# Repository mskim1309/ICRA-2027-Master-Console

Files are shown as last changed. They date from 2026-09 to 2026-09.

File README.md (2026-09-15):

# ICRA 2027 Master Console

This repository contains the design data, robot descriptions, manufacturing bill of materials, and assembly documentation for the master console presented in the accompanying ICRA 2027 paper. It is intended to support inspection, fabrication, and reproducible use of the hardware described in the paper.

> **Release status:** This repository is being prepared for the paper submission/review release. The final archival release will include the files and documentation listed below. Please use a tagged release when reproducing reported results.

## Repository layout

```text
.
├── CAD/                         # Native CAD source files
│   ├── distal_wrist/             # Distal-wrist mechanism
│   ├── grasp_module/             # Grasp/input module
│   ├── flange/                   # Robot/interface flange
│   └── console_frame/            # Main console frame and structural parts
├── URDF/                         # Robot descriptions for visualization/simulation
│   └── piper_with_custom_gripper.urdf         # PiPER arm + custom gripper urdf
├── STL/                          # Exported printable/manufacturable meshes
├── BOM/
│   └── BOM.xlsx                  # Purchased parts, quantities, and specifications
├── ASSEMBLY/
│   └── assembly_guide.pdf        # Assembly procedure and drawings
└── README.md
```

## Contents and intended use

| Directory | Contents | Intended use |
| --- | --- | --- |
| `CAD/` | Editable source models, organized by mechanical subassembly | Design inspection and modification |
| `STL/` | Mesh exports corresponding to released parts | Fabrication/3D-print preparation |
| `BOM/` | Part numbers, quantities, specifications, and procurement notes | Hardware sourcing |
| `ASSEMBLY/` | Ordered assembly instructions, fasteners, and reference drawings | Mechanical assembly |
| `URDF/` | Left and right kinematic descriptions | Visualization, simulation, and software integration |

## Reproducing the hardware

1. Review `BOM/BOM.xlsx` and obtain the listed purchased components before fabrication.
2. Fabricate the released parts from `STL/`, following the material, process, tolerance, and post-processing notes in the assembly guide.
3. Assemble the console using `ASSEMBLY/assembly_guide.pdf`. Do not infer dimensions or fasteners from mesh files when the guide specifies them.
4. Load the appropriate file from `URDF/` to verify the left/right configuration, link frames, joint axes, and mesh paths before connecting it to control software.
5. Record the repository tag/commit and any substitutions or fabrication deviations when reporting results.

## Important notes

- CAD source files are the authoritative editable design data. STL files are exports for fabrication and may be unsuitable for dimensional edits.
- All dimensions, units, coordinate-frame conventions, joint limits, mesh paths, and software dependencies will be documented with the final release. Validate them in your target simulator before operating hardware.
- The left and right consoles are separate URDF models. Do not assume that mirroring one file produces the correct frame conventions or joint signs for the other.
- This repository provides research hardware data only. Fabrication, integration, operation, and any safety assessment remain the responsibility of the user.

## Versioning and reproducibility

The version of this repository associated with the paper will be identified by a release tag. For a reproducible build or evaluation, cite the paper and record:

- repository URL and release tag (or commit SHA);
- CAD/URDF revision;
- BOM revision and any substituted components; and
- fabrication method, material, print settings, and post-processing changes.

## Citation

If you use this hardware, design data, or URDF models in academic work, please cite the associated paper:

```bibtex
@inproceedings{<citation-key>,
  title     = {<paper title>},
  author    = {<authors>},
  booktitle = {Proceedings of the IEEE International Conference on Robotics and Automation (ICRA)},
  year      = {2027},
  note      = {Paper submission / preprint; update with the final bibliographic record upon publication}
}
```

The final release will replace the placeholders above with the published citation and persistent repository URL.

## License and contact

License terms and a contact address will be added before public release. Until then, the contents are provided only for the paper-submission/review purpose; redistribution, fabrication, and commercial use require permission from the authors.

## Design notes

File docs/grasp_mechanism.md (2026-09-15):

# Grasp mechanism

Two finger levers on parallel pivots, geared to each other so they move
symmetrically. The operator squeezes them by hand.

**There is no motor and no CAN on this axis.** The levers are purely an input
device: a single magnetic rotary encoder on the lever shaft measures how far
they have been squeezed, and the console software turns that one number into the
patient-side instrument's jaw command. The two wrist axes above it are actuated;
this one is not.

## Parts

| part | file stem | role |
|---|---|---|
| Grasp lever 1 | `grasp_lever_1` | finger lever; gear teeth mesh with lever 2 |
| Grasp lever 2 | `grasp_lever_2` | finger lever; mirror of lever 1 |
| Grasp mount plate | `grasp_mount_plate` | carries the lever pair |
| Grasp pivot pins | `grasp_pin_1`, `grasp_pin_2` | lever pivots, 2 mm dia x 10.5 mm |
| Grasp sensor base | `grasp_sensor_base` | levers pivot in its centre holes; the encoder mounts on top |
| Grasp cover | `grasp_cover` | lever housing |
| MCU base | `mcu_base` | carries the XIAO board |

CAD for the two levers is in `../CAD/grasp_module/` (`grasp_lever_1`,
`grasp_lever_2`). `grasp_sensor_carrier` in the same folder holds the sensing
parts as three solids: the magnet (5 mm dia x 2 mm), the sensor IC and its PCB.
The other printed parts of the module are released as STL only.

## Kinematics

| joint | type | parent | axis | actuated |
|---|---|---|---|---|
| `gear_1_joint` | revolute | `link_2dof` | -X in the `link_2dof` frame | no — hand-driven |
| `gear_2_joint` | revolute | `link_2dof` | -X in the `link_2dof` frame | no — hand-driven |

The gear teeth constrain the pair, so one angle describes both. The software
publishes one lever angle and mirrors it onto the other (`gear_2 = -gear_1`).

**No joint limits are set in the CAD;** the travel is bounded by the parts
themselves. The URDF limits each lever joint to ±30° (0.5236 rad). Measured at
the encoder, the full travel has come out between about **20 and 36 degrees**
depending on the unit, so treat the range as something to measure per unit, not
a design constant.

The controller loads the URDF with both lever joints **locked at neutral**. That
is not bookkeeping: the dynamics library counts every unlocked joint, so leaving
the levers free changes the model's DOF count and breaks code that assumes the
arm's. Any joint added to the URDF beyond the wrist has to be locked the same way.

## Sensing

| | |
|---|---|
| encoder | AS5600-class magnetic rotary, 12-bit, 4096 counts per revolution |
| mounting | on the lever shaft, carried by `grasp_sensor_base` |
| front end | Seeed XIAO nRF52840 Sense on `mcu_base`, USB `2886:8045` |
| stream | about 167 Hz, CSV over USB CDC; the angle field is already in degrees |
| normalised output | 0.0 = fully open, 1.0 = fully closed |

Two things about this sensor decide whether the grasp feels right:

**The magnet wraps at 0/360.** The host driver unwraps the reading into a
cumulative angle, but if the lever's working range straddles the wrap point, a
squeeze right at the boundary makes the jaw jump open. Mount the magnet so the
whole travel sits away from the seam.

**The endpoints are per-unit, not per-design.** Fully-open and fully-closed
angles come from a calibration run on each assembled gripper. So do the sign and
the scale, because they depend on how the sensor is wired and which way the
magnet faces. None of these belong in the CAD or the URDF.

## Build checks

- The two levers move symmetrically. A half-tooth offset at assembly is a
  permanent bias the software cannot see.
- The encoder reading sweeps smoothly across the full lever travel. A reading
  that never moves by more than one count means the magnet is too far away or
  not centred.
- The travel does not cross the 0/360 seam.

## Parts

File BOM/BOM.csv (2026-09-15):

category | item | part_file | qty_per_hand | material_or_vendor | specification | source_of_value | notes | filament_g_per_hand_est | unit_cost_usd | cost_group_and_source
Printed part | Flange — PiPER link6 mount | STL/printable_right/flange_piper_mount.stl | 1 | PLA (Bambu PLA Basic) | 122.4 x 50.0 x 125.0 mm bbox; solid 154.46 cm3 | measured from mesh | Fixed joint link6_to_link_1dof; seats flat or wrist readings pick up a constant offset | 78.3 |  | Printed distal parts / fasteners, per console = ~60 (paper Table II)
Printed part | Wrist axis-1 yoke | STL/printable_right/wrist_axis1_yoke.stl | 1 | PLA (Bambu PLA Basic) | mass 80.84 g | URDF inertial (scaled to measured) | Carries the bases of both wrist servos (two 20 x 20 mm hole patterns in the CAD) | 81.6 |  | Printed distal parts / fasteners, per console = ~60 (paper Table II)
Printed part | Wrist axis-2 handle | STL/printable_right/wrist_axis2_handle.stl | 1 | PLA (Bambu PLA Basic) | mass 56.13 g | URDF inertial (scaled to measured) | Operator grip body | 58.9 |  | Printed distal parts / fasteners, per console = ~60 (paper Table II)
Printed part | Grasp lever 1 | STL/printable_right/grasp_lever_1.stl | 1 | PLA (Bambu PLA Basic) | 20.5 x 62.3 x 32.0 mm bbox; solid 6.02 cm3 | measured from mesh | Geared to lever 2; moves symmetrically | 7.1 |  | Printed distal parts / fasteners, per console = ~60 (paper Table II)
Printed part | Grasp lever 2 | STL/printable_right/grasp_lever_2.stl | 1 | PLA (Bambu PLA Basic) | 20.5 x 62.7 x 32.0 mm bbox; solid 6.02 cm3 | measured from mesh | Geared to lever 1 | 7.4 |  | Printed distal parts / fasteners, per console = ~60 (paper Table II)
Printed part | Grasp mount plate | STL/printable_right/grasp_mount_plate.stl | 1 | PLA (Bambu PLA Basic) | 24.0 x 42.5 x 5.0 mm bbox; solid 1.77 cm3 | measured from mesh |  | 3.2 |  | Printed distal parts / fasteners, per console = ~60 (paper Table II)
Printed part | Grasp pin 1 | STL/printable_right/grasp_pin_1.stl | 1 | PLA (Bambu PLA Basic) | pin, 2 mm dia x 10.5 mm | measured from mesh | Lever pivot | 0.1 |  | Printed distal parts / fasteners, per console = ~60 (paper Table II)
Printed part | Grasp pin 2 | STL/printable_right/grasp_pin_2.stl | 1 | PLA (Bambu PLA Basic) | pin, 2 mm dia x 10.5 mm | measured from mesh | Lever pivot | 0.1 |  | Printed distal parts / fasteners, per console = ~60 (paper Table II)
Printed part | Grasp cover | STL/printable_right/grasp_cover.stl | 1 | PLA (Bambu PLA Basic) | 63.7 x 45.6 x 21.0 mm bbox; solid 12.20 cm3 | measured from mesh |  | 18.1 |  | Printed distal parts / fasteners, per console = ~60 (paper Table II)
Printed part | MCU base | STL/printable_right/mcu_base.stl | 1 | PLA (Bambu PLA Basic) | 30.0 x 23.0 x 3.0 mm bbox; solid 1.46 cm3 | measured from mesh | Carries the XIAO board | 2.6 |  | Printed distal parts / fasteners, per console = ~60 (paper Table II)
Printed part | Grasp sensor base | STL/printable_right/grasp_sensor_base.stl | 1 | PLA (Bambu PLA Basic) | 30 x 50 x 9.5 mm plate | measured from mesh | Grasp levers pivot in the centre holes; the sensor mounts on top. Released as STL only | 5.6 |  | Printed distal parts / fasteners, per console = ~60 (paper Table II)
Structure | Console frame | CAD/console_frame/console_frame_v2.step | 1 | PLA | 920 x 920 x 784 mm; single solid | measured from CAD | One per console (not per hand). Too large to print in one piece - needs splitting; pieces not in this release |  | 644 | Frame, arm supports, and mounts, 1 = ~644 (paper Table II)
Actuator | MF4005-V2 CAN servo |  | 2 | LKTech / MyActuator | 12 V bus (12.3-12.5 V measured); CAN; multi-turn absolute encoder; torque constant 0.05 N*m/A (25T) / 0.07 N*m/A (40T) per datasheet | datasheet + measured on the rig | Command and reply share arbitration ID 0x140+ID - set IDs before assembly. Right wrist: ID 2 and 4. Left wrist: ID 2 and 6. |  | 180 | Direct-drive wrist actuators, 4 = ~720 (paper Table II); 720 / 4
Sensor | Magnetic rotary encoder (AS5600 class) |  | 1 | ams-OSRAM AS5600 IC on a generic breakout (diametric magnet usually supplied) | 12-bit absolute; 4096 counts per revolution | firmware/host driver | Reads the geared lever pair as one grasp angle |  |  | Grasp sensors + distal MCUs, 2+2 = 40 (paper Table II)
Controller | Seeed XIAO nRF52840 Sense |  | 1 | Seeed Studio | USB 2886:8045; streams grasp angle in degrees over USB CDC | enumeration log | Firmware not part of this release |  |  | Grasp sensors + distal MCUs, 2+2 = 40 (paper Table II)
Assembly | Gripper assembled mass |  | 1 |  | 207 g | measured | URDF inertials were uniformly scaled to this (URDF sum 203.0 g, factor 1.0197)
Reference only | AgileX PiPER 6-DOF arm |  | 1 | AgileX | Leader arm this gripper mounts on |  | Vendor CAD not redistributed here |  | 1999 | PiPER 6-DoF arms, 2 = 3,998 (paper Table II); 3,998 / 2
Reference only | Franka FR3 |  | 1 | Franka Robotics | Patient-side platform |  | Not part of the leader design
Reference only | Feetech STS3215 bus servo |  | 5 | Feetech / Waveshare | 1 Mbaud TTL bus; approx. 30 kgf*cm at 12 V; 1:345 gearbox | vendor spec + bring-up log | Used in the patient-side EndoWrist instrument, not in the leader gripper

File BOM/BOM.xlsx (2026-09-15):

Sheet: BOM
ROSOTA Leader Gripper — Bill of Materials
Quantities are per hand (one gripper). A full master console uses one right-hand and one left-hand unit, so the console column is 2x the per-hand quantity — except Structure rows, which are one per console.
Legend: 'Part file' stems match the CAD/ and STL/ file names. Blue rows are reference hardware, not part of this release.
No. | Category | Item | Part file | Qty / hand | Qty / console | Material or vendor | Specification | Source of value | Notes | Filament / hand (g, est.) | Unit cost (USD) | Cost group and source
1 | Printed part | Flange — PiPER link6 mount | STL/printable_right/flange_piper_mount.stl | 1 |  | PLA (Bambu PLA Basic) | 122.4 x 50.0 x 125.0 mm bbox; solid 154.46 cm3 | measured from mesh | Fixed joint link6_to_link_1dof; seats flat or wrist readings pick up a constant offset | 78.3 |  | Printed distal parts / fasteners, per console = ~60 (paper Table II)
2 | Printed part | Wrist axis-1 yoke | STL/printable_right/wrist_axis1_yoke.stl | 1 |  | PLA (Bambu PLA Basic) | mass 80.84 g | URDF inertial (scaled to measured) | Carries the bases of both wrist servos (two 20 x 20 mm hole patterns in the CAD) | 81.6 |  | Printed distal parts / fasteners, per console = ~60 (paper Table II)
3 | Printed part | Wrist axis-2 handle | STL/printable_right/wrist_axis2_handle.stl | 1 |  | PLA (Bambu PLA Basic) | mass 56.13 g | URDF inertial (scaled to measured) | Operator grip body | 58.9 |  | Printed distal parts / fasteners, per console = ~60 (paper Table II)
4 | Printed part | Grasp lever 1 | STL/printable_right/grasp_lever_1.stl | 1 |  | PLA (Bambu PLA Basic) | 20.5 x 62.3 x 32.0 mm bbox; solid 6.02 cm3 | measured from mesh | Geared to lever 2; moves symmetrically | 7.1 |  | Printed distal parts / fasteners, per console = ~60 (paper Table II)
5 | Printed part | Grasp lever 2 | STL/printable_right/grasp_lever_2.stl | 1 |  | PLA (Bambu PLA Basic) | 20.5 x 62.7 x 32.0 mm bbox; solid 6.02 cm3 | measured from mesh | Geared to lever 1 | 7.4 |  | Printed distal parts / fasteners, per console = ~60 (paper Table II)
6 | Printed part | Grasp mount plate | STL/printable_right/grasp_mount_plate.stl | 1 |  | PLA (Bambu PLA Basic) | 24.0 x 42.5 x 5.0 mm bbox; solid 1.77 cm3 | measured from mesh |  | 3.2 |  | Printed distal parts / fasteners, per console = ~60 (paper Table II)
7 | Printed part | Grasp pin 1 | STL/printable_right/grasp_pin_1.stl | 1 |  | PLA (Bambu PLA Basic) | pin, 2 mm dia x 10.5 mm | measured from mesh | Lever pivot | 0.1 |  | Printed distal parts / fasteners, per console = ~60 (paper Table II)
8 | Printed part | Grasp pin 2 | STL/printable_right/grasp_pin_2.stl | 1 |  | PLA (Bambu PLA Basic) | pin, 2 mm dia x 10.5 mm | measured from mesh | Lever pivot | 0.1 |  | Printed distal parts / fasteners, per console = ~60 (paper Table II)
9 | Printed part | Grasp cover | STL/printable_right/grasp_cover.stl | 1 |  | PLA (Bambu PLA Basic) | 63.7 x 45.6 x 21.0 mm bbox; solid 12.20 cm3 | measured from mesh |  | 18.1 |  | Printed distal parts / fasteners, per console = ~60 (paper Table II)
10 | Printed part | MCU base | STL/printable_right/mcu_base.stl | 1 |  | PLA (Bambu PLA Basic) | 30.0 x 23.0 x 3.0 mm bbox; solid 1.46 cm3 | measured from mesh | Carries the XIAO board | 2.6 |  | Printed distal parts / fasteners, per console = ~60 (paper Table II)
11 | Printed part | Grasp sensor base | STL/printable_right/grasp_sensor_base.stl | 1 |  | PLA (Bambu PLA Basic) | 30 x 50 x 9.5 mm plate | measured from mesh | Grasp levers pivot in the centre holes; the sensor mounts on top. Released as STL only | 5.6 |  | Printed distal parts / fasteners, per console = ~60 (paper Table II)
12 | Structure | Console frame | CAD/console_frame/console_frame_v2.step | 1 |  | PLA | 920 x 920 x 784 mm; single solid | measured from CAD | One per console (not per hand). Too large to print in one piece - needs splitting; pieces not in this release |  | 644 | Frame, arm supports, and mounts, 1 = ~644 (paper Table II)
13 | Actuator | MF4005-V2 CAN servo |  | 2 |  | LKTech / MyActuator | 12 V bus (12.3-12.5 V measured); CAN; multi-turn absolute encoder; torque constant 0.05 N*m/A (25T) / 0.07 N*m/A (40T) per datasheet | datasheet + measured on the rig | Command and reply share arbitration ID 0x140+ID - set IDs before assembly. Right wrist: ID 2 and 4. Left wrist: ID 2 and 6. |  | 180 | Direct-drive wrist actuators, 4 = ~720 (paper Table II); 720 / 4
14 | Sensor | Magnetic rotary encoder (AS5600 class) |  | 1 |  | ams-OSRAM AS5600 IC on a generic breakout (diametric magnet usually supplied) | 12-bit absolute; 4096 counts per revolution | firmware/host driver | Reads the geared lever pair as one grasp angle |  |  | Grasp sensors + distal MCUs, 2+2 = 40 (paper Table II)
15 | Controller | Seeed XIAO nRF52840 Sense |  | 1 |  | Seeed Studio | USB 2886:8045; streams grasp angle in degrees over USB CDC | enumeration log | Firmware not part of this release |  |  | Grasp sensors + distal MCUs, 2+2 = 40 (paper Table II)
16 | Assembly | Gripper assembled mass |  | 1 |  |  | 207 g | measured | URDF inertials were uniformly scaled to this (URDF sum 203.0 g, factor 1.0197)
17 | Reference only | AgileX PiPER 6-DOF arm |  | 1 |  | AgileX | Leader arm this gripper mounts on |  | Vendor CAD not redistributed here |  | 1999 | PiPER 6-DoF arms, 2 = 3,998 (paper Table II); 3,998 / 2
18 | Reference only | Franka FR3 |  | 1 |  | Franka Robotics | Patient-side platform |  | Not part of the leader design
19 | Reference only | Feetech STS3215 bus servo |  | 5 |  | Feetech / Waveshare | 1 Mbaud TTL bus; approx. 30 kgf*cm at 12 V; 1:345 gearbox | vendor spec + bring-up log | Used in the patient-side EndoWrist instrument, not in the leader gripper
 |  | Printed parts per hand |  |  |  |  |  |  | count of rows in the Printed part category
 |  | Assembled gripper mass |  | 207 |  | g |  | measured | URDF inertials uniformly scaled to this (URDF sum 203.0 g, factor 1.0197)
 |  | Printed filament per console (g, est.) |  |  |  |  |  |  | right + left sets; STL volume/area estimate calibrated on the real print record gripper1,2 sensor base.gcode.3mf (P2S, 0.20 mm, 2 walls, 15 % infill, PLA) - not a slicer result
 |  | Console hardware cost (USD), as in the paper, Table II
 |  | Item |  | Qty. | Cost (USD) | Note
 |  | PiPER 6-DoF arms |  | 2 | 3998
 |  | Direct-drive wrist actuators |  | 4 | 720 | approximate
 |  | Grasp sensors + distal MCUs |  | 2+2 | 40
 |  | Printed distal parts / fasteners |  | - | 60 | approximate
 |  | Foot pedals |  | 2 | 40 | approximate
 |  | Frame, arm supports, and mounts |  | 1 | 644 | approximate
 |  | Proposed console total |  |  |  | paper: ~5,502
 |  | Excludes display, workstation, labor and patient side (as in the paper). Foot pedals and arm supports are not itemised in this BOM.

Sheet: Actuator_Sensor_Specs
Actuator and sensor specifications
'measured' = read off the running rig. 'datasheet'/'vendor' = published by the maker.
Device | Role | Parameter | Value | Source
MF4005-V2 | Wrist axes 1 and 2 (2 per hand) | Bus | CAN | design
MF4005-V2 |  | Arbitration ID | 0x140 + motor ID (command and reply share it) | bring-up log
MF4005-V2 |  | Motor IDs in use | Right wrist 2 and 4; left wrist 2 and 6 | bring-up log
MF4005-V2 |  | Supply voltage | 12.3 - 12.5 V under load | measured
MF4005-V2 |  | Torque constant (datasheet) | 0.05 N*m/A (25T) / 0.07 N*m/A (40T) | datasheet
MF4005-V2 |  | Torque constant (measured) | 0.0613 N*m/A - between the two datasheet variants | measured
MF4005-V2 |  | Encoder | multi-turn absolute | datasheet
MF4005-V2 |  | Case temperature in use | 36 - 37 C | measured
MF4005-V2 |  | Winding temperature | not measured - the reported value is case temperature | measured
Magnetic rotary encoder (AS5600 class) | Grasp angle (1 per hand) - hand-driven, no actuator on this axis | Resolution | 12-bit, 4096 counts per revolution | host driver
Magnetic rotary encoder (AS5600 class) |  | Output | angle in degrees, already converted on the board | host driver
Magnetic rotary encoder (AS5600 class) |  | Update rate | approx. 167 Hz | host driver
Magnetic rotary encoder (AS5600 class) |  | Normalised output | 0.0 = fully open, 1.0 = fully closed | host driver
Magnetic rotary encoder (AS5600 class) |  | Wrap behaviour | reading wraps at 0/360 deg and is unwrapped on the host - keep the lever travel off the seam | host driver
Magnetic rotary encoder (AS5600 class) |  | Open/closed endpoints | per unit, set by calibration - not a design constant. Measured travel is roughly 20-30 deg depending on the unit | measured
Magnetic rotary encoder (AS5600 class) |  | Exact part number | ams-OSRAM AS5600 (IC). The breakout-board vendor used in the build is not recorded | ams-OSRAM product page
Seeed XIAO nRF52840 Sense | Sensor front end (1 per hand) | USB ID | 2886:8045 | enumeration log
Seeed XIAO nRF52840 Sense |  | Host interface | USB CDC serial | design
Seeed XIAO nRF52840 Sense |  | Firmware | not included in this release | -
Feetech STS3215 | Patient-side EndoWrist instrument (reference only - not in the leader gripper) | Bus | TTL serial, 1,000,000 bps (factory default) | vendor + bring-up log
Feetech STS3215 |  | Output torque | approx. 30 kgf*cm at 12 V, through the 1:345 gearbox | vendor
Feetech STS3215 |  | Gear ratio | 1:345 | vendor
Feetech STS3215 |  | Count in instrument | 5 servos pulling 5 wires, driving pitch, yaw and jaw (an earlier roadmap specified 4 servos for 4 axes - the as-built instrument uses 5) | as-built doc

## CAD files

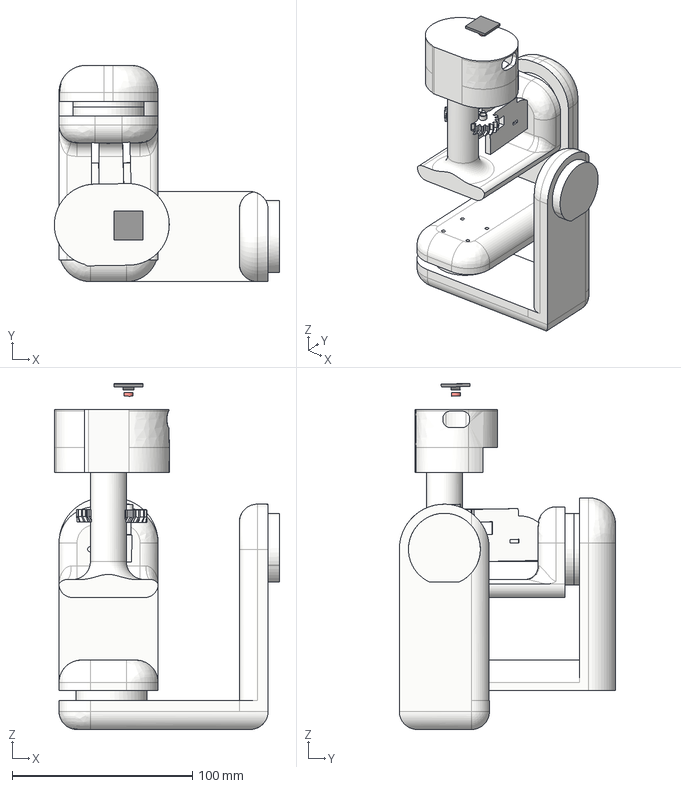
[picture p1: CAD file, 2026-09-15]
CAD/gripper_2dof_assembly.step
125.0 x 120.0 x 191.9 mm
link_1dof
link_1dof_2dof
link_2dof
link_gear_1
link_gear_2
grasp_sensing_viz

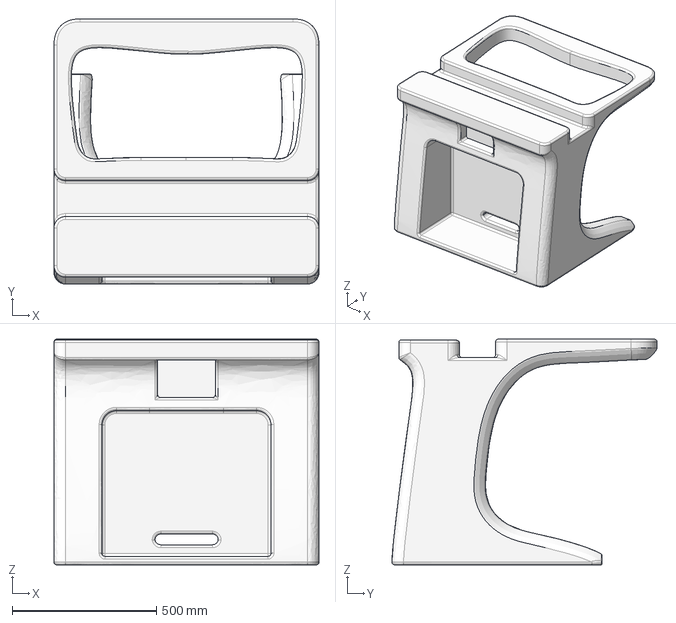
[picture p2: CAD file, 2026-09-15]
CAD/console_frame/console_frame_v2.step
920.0 x 920.5 x 784.1 mm

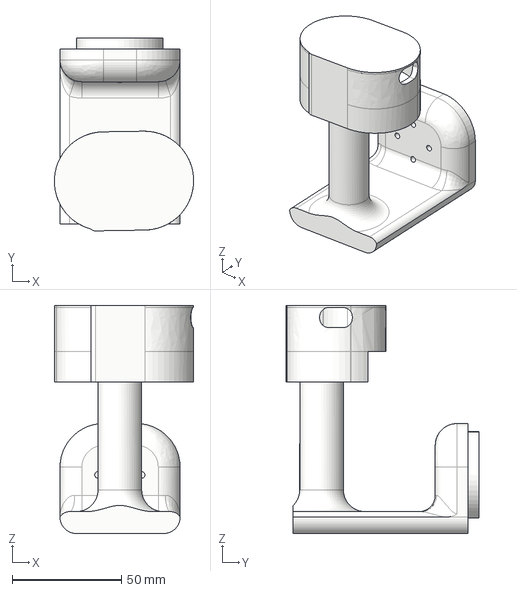
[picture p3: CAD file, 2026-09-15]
CAD/distal_wrist/wrist_axis2_handle.step
63.7 x 88.2 x 104.3 mm

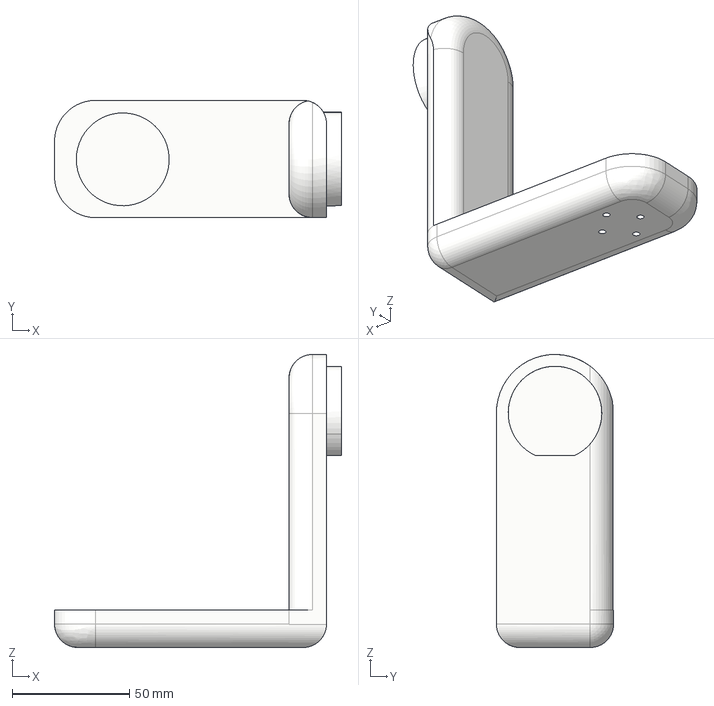
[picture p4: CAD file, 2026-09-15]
CAD/flange/flange_piper_mount.step
122.4 x 50.0 x 125.0 mm

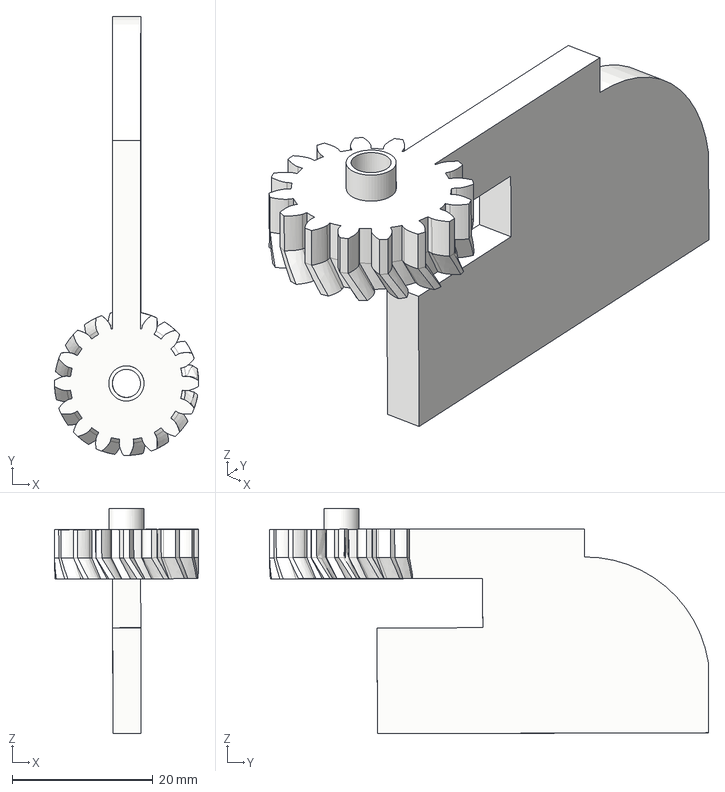
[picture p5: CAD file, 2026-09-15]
CAD/grasp_module/grasp_lever_2.step
20.5 x 62.3 x 32.0 mm

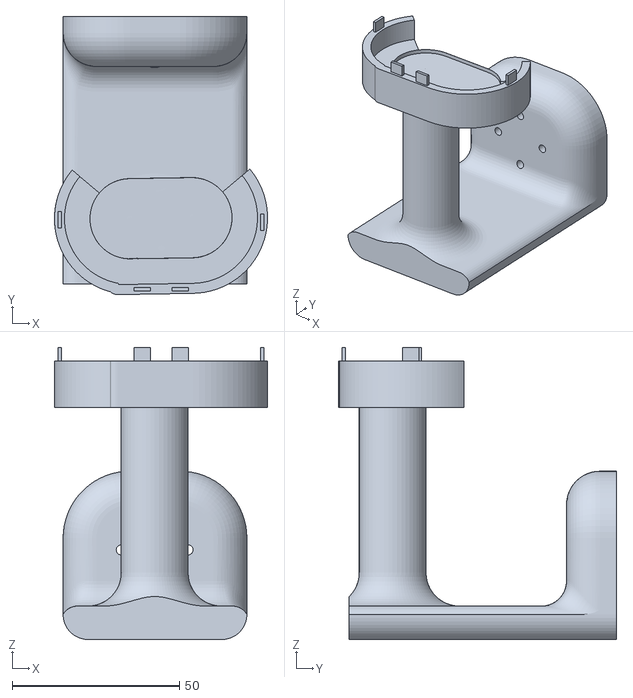
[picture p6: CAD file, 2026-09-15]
STL/printable_right/wrist_axis2_handle.stl
63.7 x 83.2 x 87.3

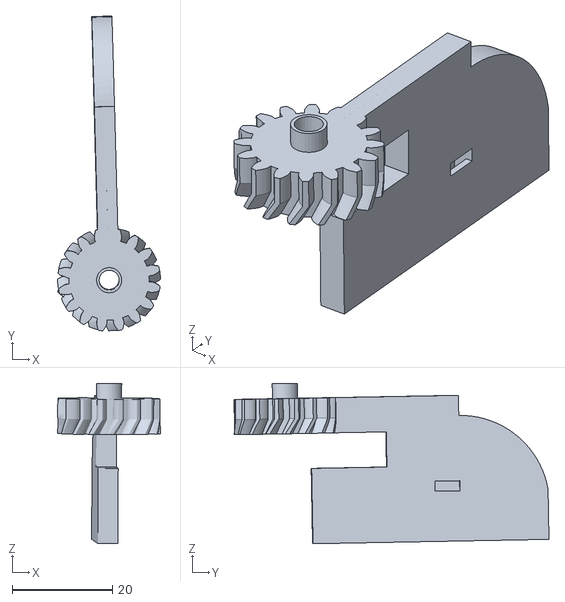
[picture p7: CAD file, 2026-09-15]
STL/urdf_meshes/link_gear_1.stl
20.5 x 62.7 x 32.0

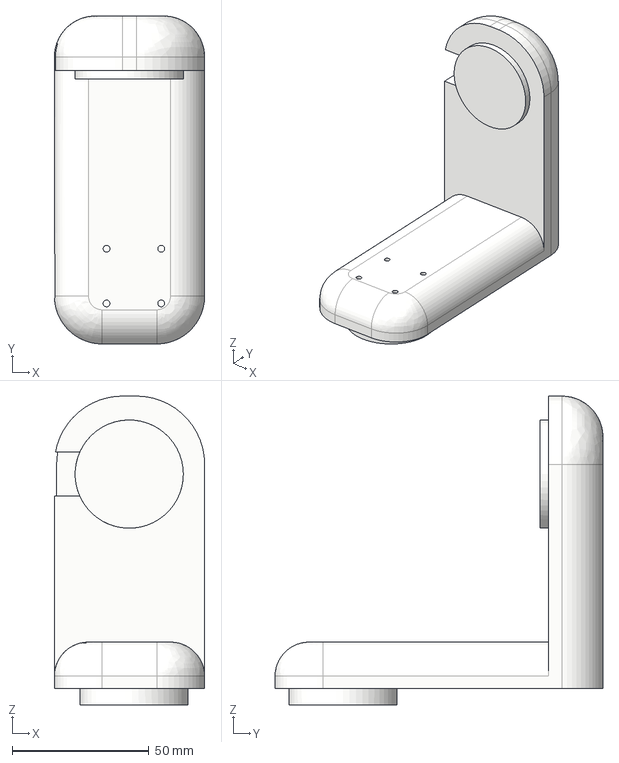
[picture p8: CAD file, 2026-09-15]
CAD/distal_wrist/wrist_axis1_yoke.step
55.0 x 120.0 x 113.0 mm

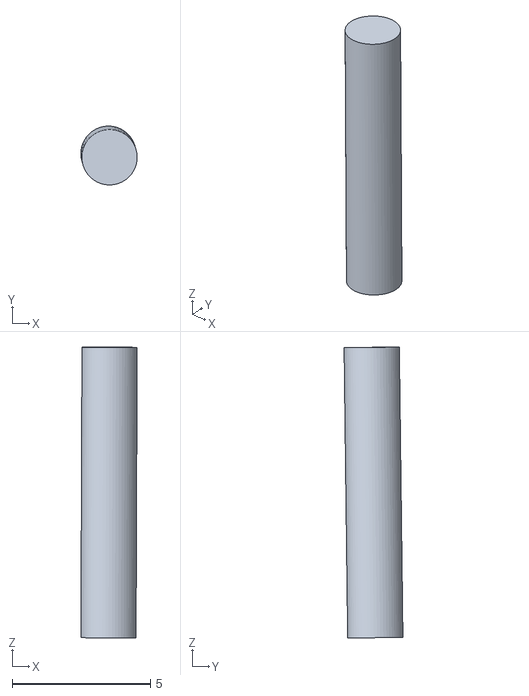
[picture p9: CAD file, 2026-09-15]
STL/printable_left/grasp_pin_2_L.stl
2.04 x 2.13 x 10.5

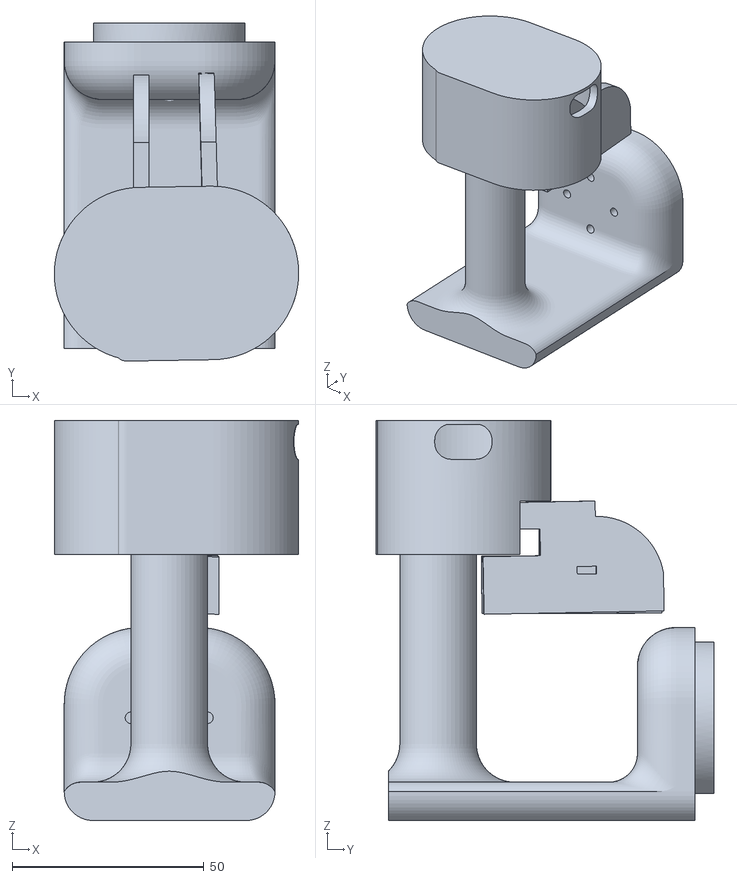
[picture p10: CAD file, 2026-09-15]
STL/urdf_meshes/link_2dof.stl
63.7 x 88.2 x 104.3

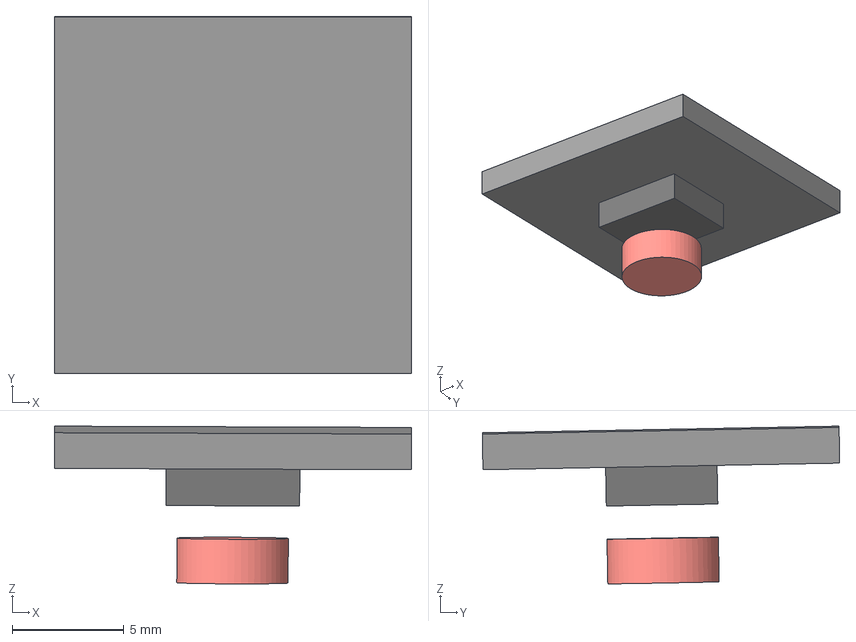
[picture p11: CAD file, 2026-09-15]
CAD/grasp_module/grasp_sensor_carrier.step
16.0 x 16.0 x 7.07 mm

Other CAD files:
STL/printable_left/grasp_lever_1_L.stl
CAD/grasp_module/grasp_lever_1.step
STL/printable_right/wrist_axis1_yoke.stl
STL/printable_left/grasp_pin_1_L.stl
STL/urdf_meshes/link_1dof.stl
STL/printable_left/grasp_lever_2_L.stl
CAD/console_frame/console_frame_v2.f3d
CAD/distal_wrist/wrist_axis1_yoke.f3d
CAD/distal_wrist/wrist_axis2_handle.f3d
CAD/flange/flange_piper_mount.f3d
CAD/grasp_module/grasp_lever_1.f3d
CAD/grasp_module/grasp_lever_2.f3d
CAD/grasp_module/grasp_sensor_carrier.f3d
CAD/gripper_2dof_assembly.f3d
STL/console_frame/console_frame_v2.stl
STL/printable_left/flange_piper_mount_L.stl
STL/printable_left/grasp_cover_L.stl
STL/printable_left/grasp_mount_plate_L.stl
STL/printable_left/grasp_sensor_base_L.stl
STL/printable_left/mcu_base_L.stl
STL/printable_left/wrist_axis1_yoke_L.stl
STL/printable_left/wrist_axis2_handle_L.stl
STL/printable_right/flange_piper_mount.stl
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

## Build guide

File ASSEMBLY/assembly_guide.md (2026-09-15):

# Assembly guide — ROSOTA leader gripper (2-DOF wrist + grasp levers)

## 0. Before you start

Print every part in `STL/printable_right/` for a right-hand unit, or
`STL/printable_left/` for a left-hand unit. A full console needs one of each.

| setting | value |
|---|---|
| material | PLA (Bambu PLA Basic) |
| layer height | 0.20 mm |
| walls / infill | 2 walls, 15 % cubic infill |
| supports | on |

Fig. 1 shows the assembled right-hand gripper with every printed part named.

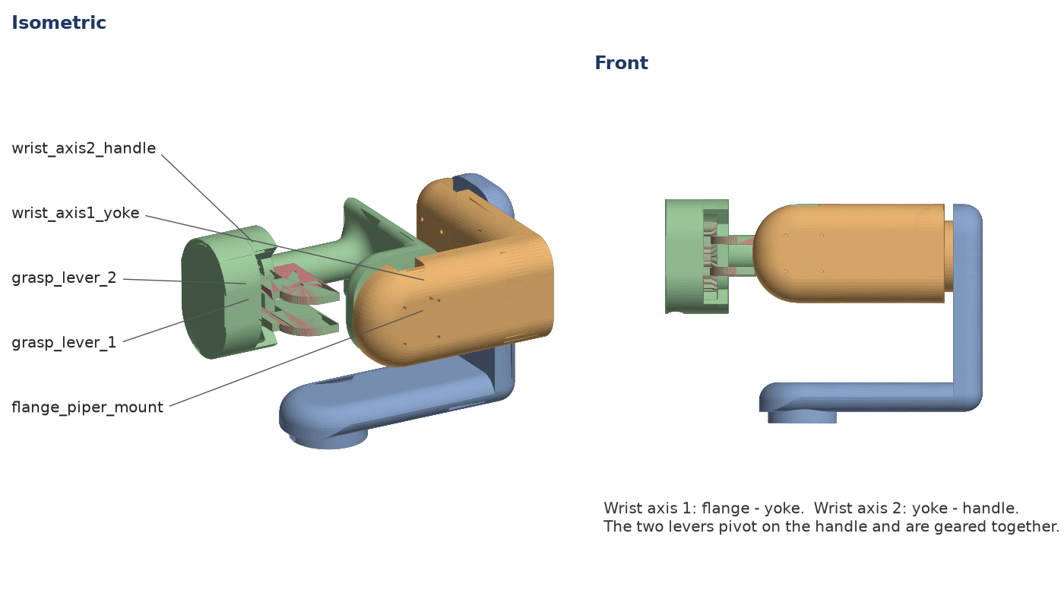
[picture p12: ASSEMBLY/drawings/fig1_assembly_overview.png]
Fig. 1. Assembled right-hand gripper (meshes from STL/urdf_meshes placed at the URDF link origins).


## 1. Flange to the arm

1. Bolt `flange_piper_mount` onto the PiPER `link6` face through the four
   holes on PCD 20 mm in its base plate (Fig. 3).
2. Check that the flange seats flat — this joint is fixed in the URDF, so any
   tilt here shows up as a constant offset in every wrist reading.

## 2. Wrist axis 1

The MF4005-V2 mounting faces are shown in Fig. 2.

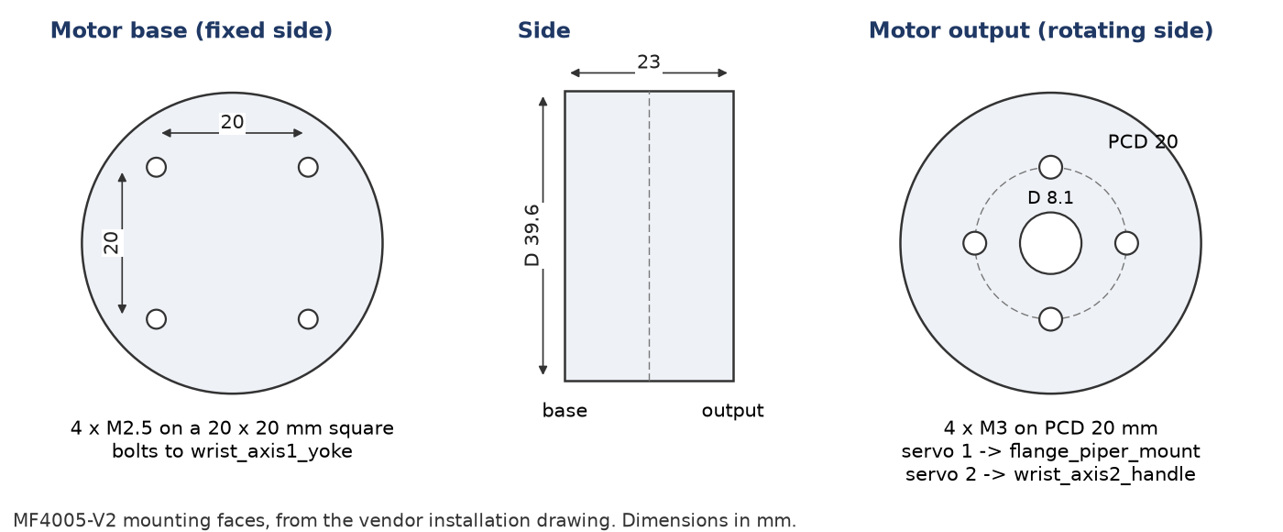
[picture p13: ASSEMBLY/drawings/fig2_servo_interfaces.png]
Fig. 2. MF4005-V2 mounting faces and the printed part each face is fixed to.


1. Seat the first **MF4005-V2** servo in `wrist_axis1_yoke`, motor base against
   the yoke.
2. Attach the servo output to `flange_piper_mount`.
3. Set the motor's CAN ID **before** it goes into the bundle — the right wrist
   uses IDs **2 and 4**, the left wrist IDs **2 and 6**. MF4005 replies on the
   same arbitration ID it is queried on (`0x140+ID`), so two motors sharing an
   ID on one bus cannot be told apart afterwards.

## 3. Wrist axis 2

1. Seat the second MF4005-V2 in `wrist_axis1_yoke`.
2. Attach `wrist_axis2_handle` to its output.
3. Route both motor cables along the outside of the handle.

## 4. Grasp module

1. Fit `grasp_lever_1` and `grasp_lever_2` onto `grasp_mount_plate` with
   `grasp_pin_1` / `grasp_pin_2`.
2. Mesh the lever gear teeth so the two levers move symmetrically. The console
   software reads the pair as a single grasp angle, so a half-tooth offset is a
   permanent bias.
3. Mount the magnetic rotary encoder on the lever shaft. Set the magnet gap so
   the reading changes smoothly across the full lever travel — a reading that
   never moves by more than one LSB means the magnet is too far away or not
   centred.
4. Fit `grasp_cover`.

## 5. Electronics

1. Mount the **Seeed XIAO nRF52840 Sense** on `mcu_base`.
2. Wire the encoder to the XIAO.
3. The XIAO enumerates as USB `2886:8045` and streams the grasp angle in
   degrees over USB CDC.

## 6. Checks before use

- [ ] Both MF4005 answer on their intended IDs, on the intended bus.
- [ ] Bus voltage reads 12.3–12.5 V under load.
- [ ] The encoder sweeps its full range over the lever travel, with no jumps.
- [ ] Assembled gripper mass is close to 207 g — a large difference means a part
      was printed with different settings, and the URDF inertials will be off.

## 7. Reference drawings

Overall dimensions of the right-hand parts. The left-hand parts in
`STL/printable_left/` are their mirror images.

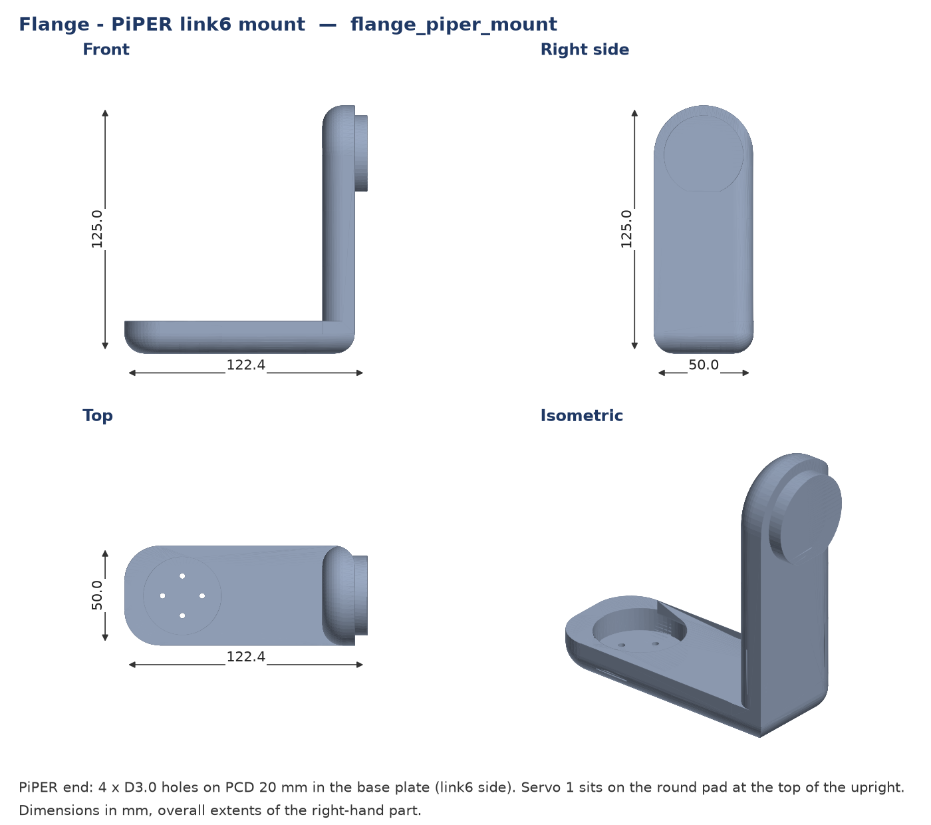
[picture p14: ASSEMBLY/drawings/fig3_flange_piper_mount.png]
Fig. 3. flange_piper_mount.


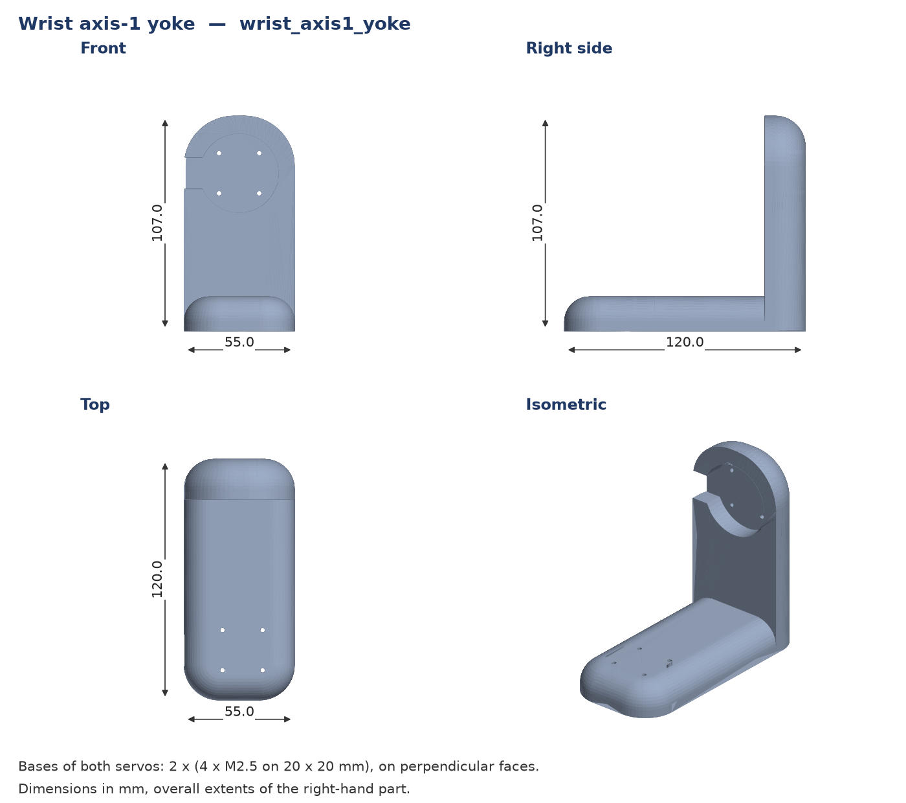
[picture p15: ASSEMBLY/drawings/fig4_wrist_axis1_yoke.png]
Fig. 4. wrist_axis1_yoke.


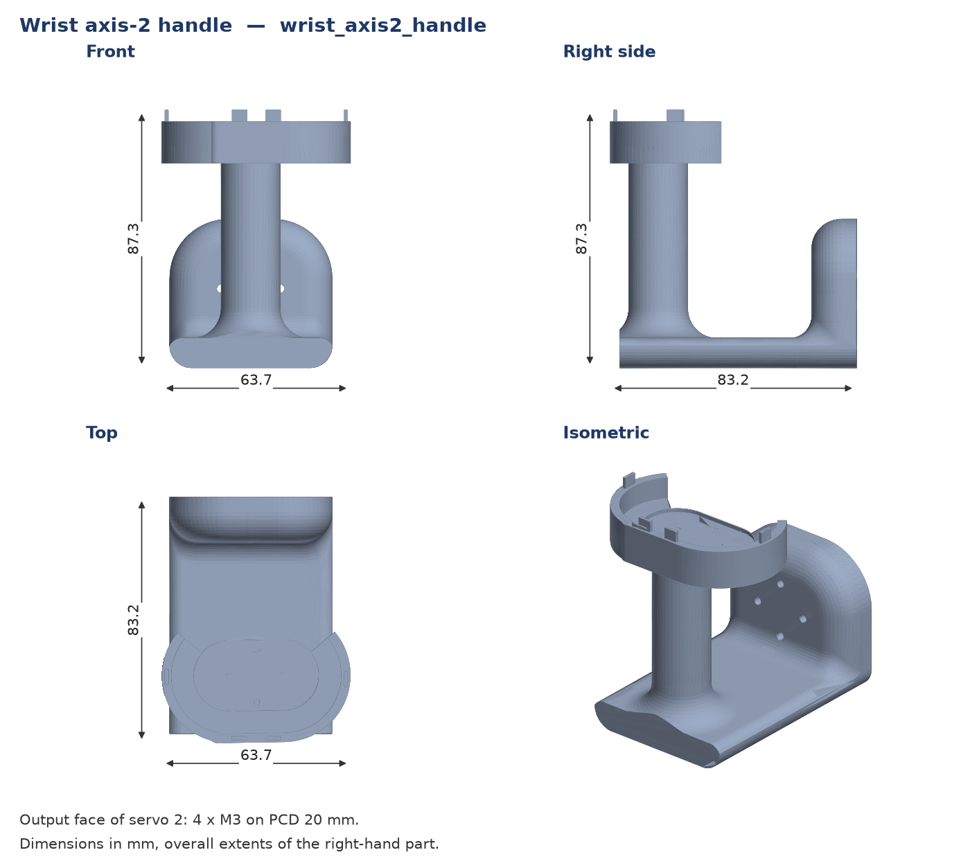
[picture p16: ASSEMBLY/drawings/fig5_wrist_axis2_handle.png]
Fig. 5. wrist_axis2_handle.


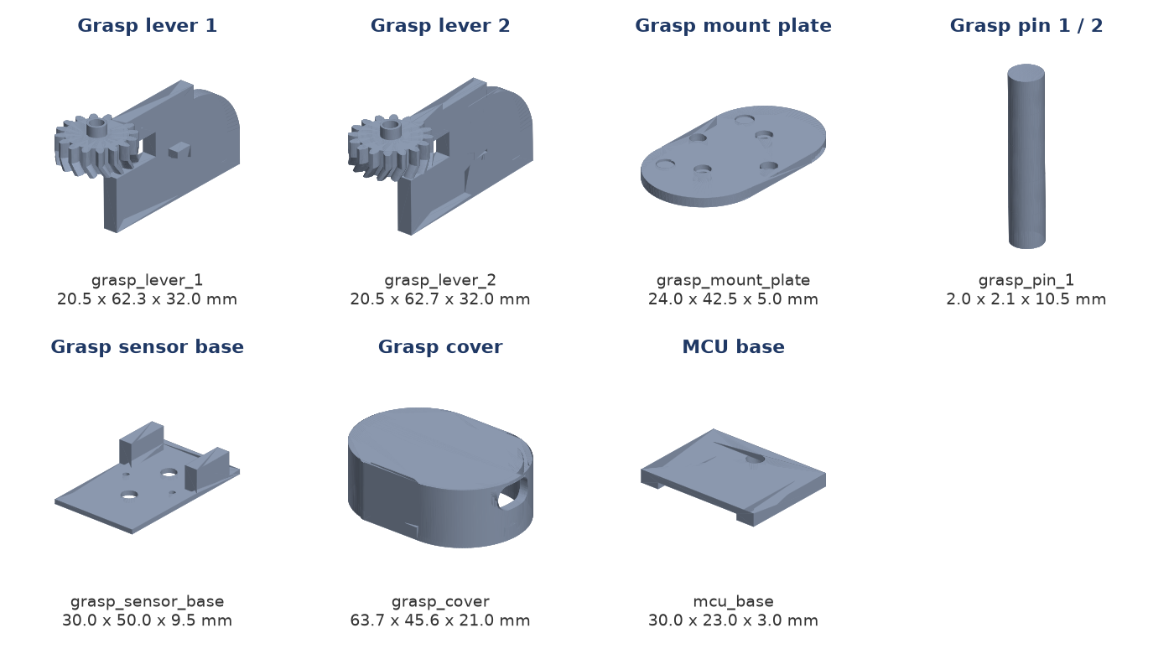
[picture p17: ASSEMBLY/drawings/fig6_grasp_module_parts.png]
Fig. 6. Grasp-module parts.


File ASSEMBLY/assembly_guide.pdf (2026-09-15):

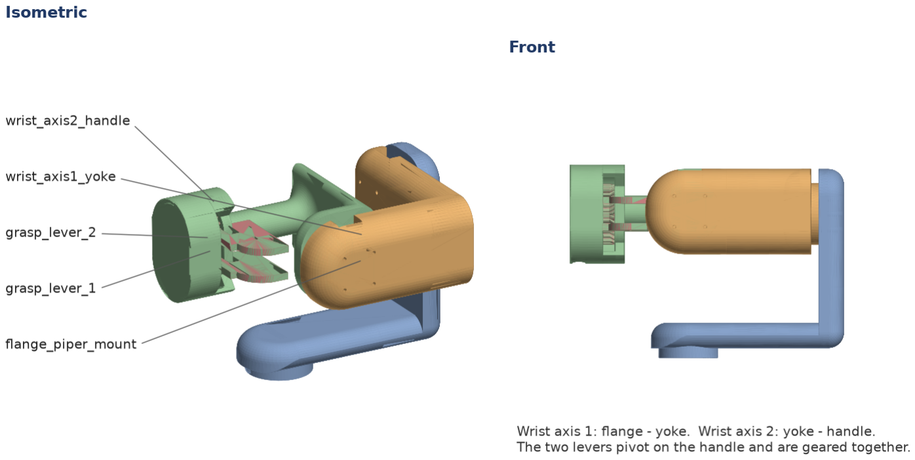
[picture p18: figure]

ROSOTA leader gripper - assembly guide (draft) | Page 1

# Assembly guide — ROSOTA leader gripper (2-DOF wrist + grasp levers)

## 0. Before you start

Print every part in STL/printable_right/ for a right-hand unit, or STL/printable_left/ for a left-hand unit. A full console needs one of each.

setting | value
material | PLA (Bambu PLA Basic)
layer height | 0.20 mm
walls / infill | 2 walls, 15 % cubic infill
supports | on

Fig. 1 shows the assembled right-hand gripper with every printed part named.

Fig. 1. Assembled right-hand gripper (meshes from STL/urdf_meshes placed at the URDF link origins).

## 1. Flange to the arm

1 Bolt flange_piper_mount onto the PiPER link6 face through the four holes on PCD 20 mm in its base plate (Fig. 3).
2 Check that the flange seats flat — this joint is fixed in the URDF, so any tilt here shows up as a constant offset in every wrist reading.

## 2. Wrist axis 1

The MF4005-V2 mounting faces are shown in Fig. 2.

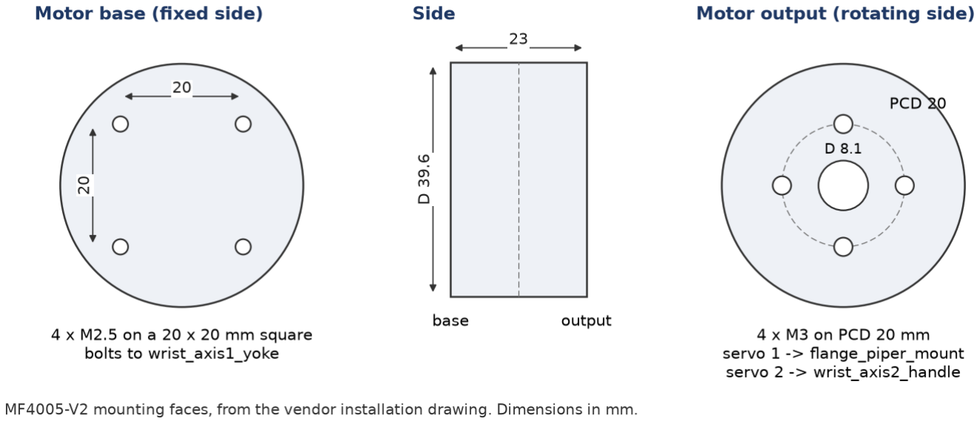
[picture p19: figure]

Fig. 2. MF4005-V2 mounting faces and the printed part each face is fixed to.
1 Seat the first MF4005-V2 servo in wrist_axis1_yoke, motor base against the yoke.
2 Attach the servo output to flange_piper_mount.
3 Set the motor's CAN ID before it goes into the bundle — the right wrist uses IDs 2 and 4, the left wrist IDs 2 and 6. MF4005 replies on the same arbitration ID it is queried on (0x140+ID), so two motors sharing an ID on one bus cannot be told apart afterwards.

## 3. Wrist axis 2

1 Seat the second MF4005-V2 in wrist_axis1_yoke.
2 Attach wrist_axis2_handle to its output.
3 Route both motor cables along the outside of the handle.

## 4. Grasp module

1 Fit grasp_lever_1 and grasp_lever_2 onto grasp_mount_plate with grasp_pin_1 / grasp_pin_2.
2 Mesh the lever gear teeth so the two levers move symmetrically. The console software reads the pair as a single grasp angle, so a half-tooth offset is a permanent bias.
3 Mount the magnetic rotary encoder on the lever shaft. Set the magnet gap so the reading changes smoothly across the full lever travel — a reading that never moves by more than one LSB means the magnet is too far away or not centred.

4 Fit grasp_cover.

## 5. Electronics

1 Mount the Seeed XIAO nRF52840 Sense on mcu_base.
2 Wire the encoder to the XIAO.
3 The XIAO enumerates as USB 2886:8045 and streams the grasp angle in degrees over USB CDC.

## 6. Checks before use

[ ] Both MF4005 answer on their intended IDs, on the intended bus.
[ ] Bus voltage reads 12.3–12.5 V under load.
[ ] The encoder sweeps its full range over the lever travel, with no jumps.
[ ] Assembled gripper mass is close to 207 g — a large difference means a part was printed with different settings, and the URDF inertials will be off.

## 7. Reference drawings

Overall dimensions of the right-hand parts. The left-hand parts in STL/printable_left/ are their mirror images.

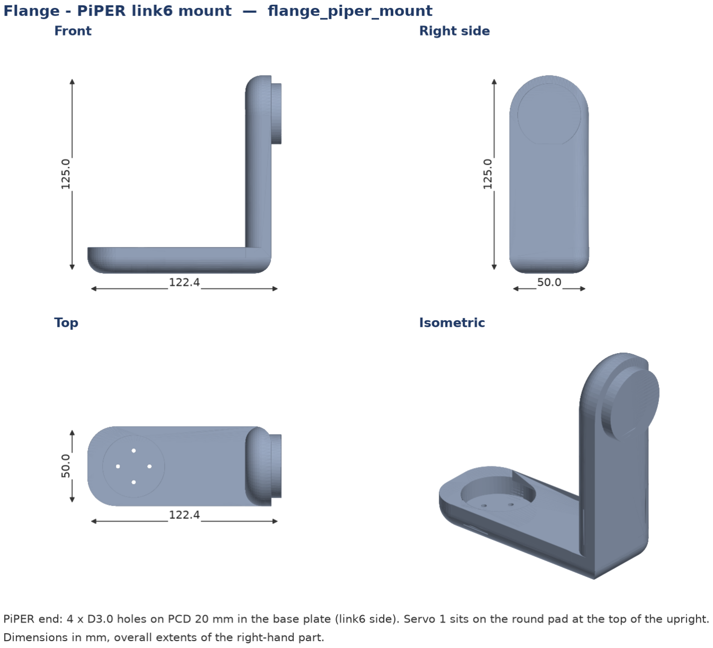
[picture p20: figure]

Fig. 3. flange_piper_mount.


Fig. 4. wrist_axis1_yoke.

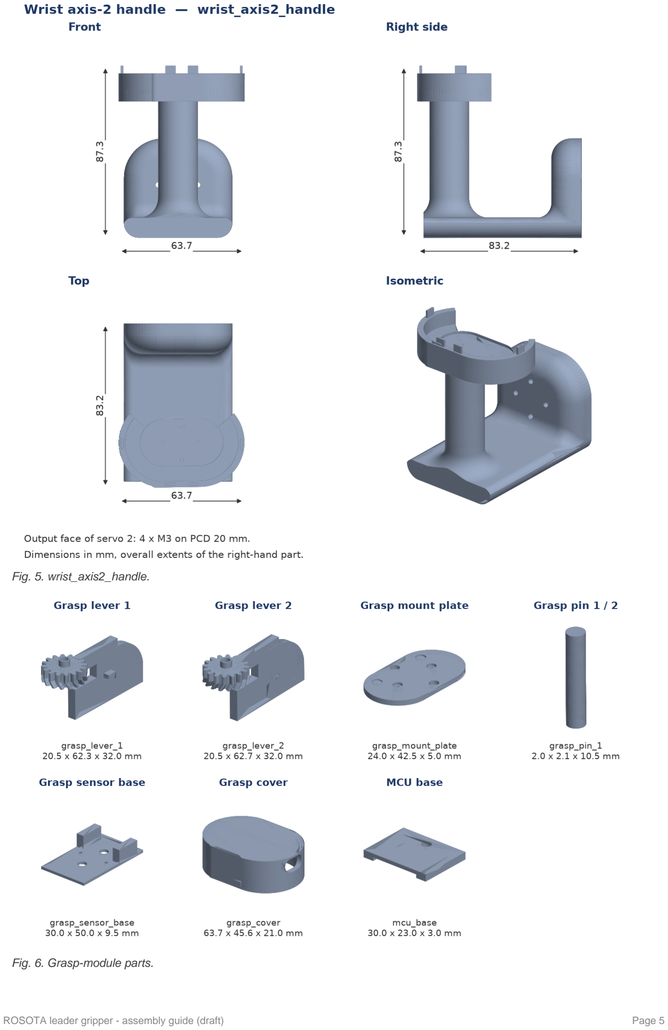
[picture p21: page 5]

Fig. 5. wrist_axis2_handle.

Fig. 6. Grasp-module parts.

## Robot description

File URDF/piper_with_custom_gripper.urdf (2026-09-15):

<?xml version="1.0" encoding="utf-8"?>
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
<robot name="piper">
  <link name="dummy_link"/>
  <joint name="base_to_dummy" type="fixed">
    <parent link="dummy_link"/>
    <child link="base_link"/>
    <origin xyz="0 0 0" rpy="0 0 0"/>
  </joint>

  <link name="base_link">
    <inertial>
      <origin xyz="-0.00473641164191482 2.56829134630247E-05 0.041451518036016" rpy="0 0 0" />
      <mass value="1.02" />
      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
    </inertial>
    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
  </link>

  <link name="link1">
    <inertial>
      <origin xyz="0.000121504734057468 0.000104632162460536 -0.00438597309559853" rpy="0 0 0" />
      <mass value="0.71" />
      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
    </inertial>
    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
  </link>
  <joint name="joint1" type="revolute">
    <origin xyz="0 0 0.123" rpy="0 0 0" />
    <parent link="base_link" />
    <child link="link1" />
    <axis xyz="0 0 1" />
    <limit lower="-2.618" upper="2.618" effort="100" velocity="5" />
  </joint>
  <link name="link2">
    <inertial>
      <origin xyz="0.198666145229743 -0.010926924140076 0.00142121714502687" rpy="0 0 0" />
      <mass value="1.17" />
      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
    </inertial>
    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
  </link>
  <joint name="joint2" type="revolute">
    <origin xyz="0 0 0" rpy="1.5708 -0.1359 -3.1416" />
      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
    <parent link="link1" />
    <child link="link2" />
    <axis xyz="0 0 1" />
    <limit lower="0" upper="3.14" effort="100" velocity="5" />
  </joint>
  <link name="link3">
    <inertial>
      <origin xyz="-0.0202737662122021 -0.133914995944595 -0.000458682652737356" rpy="0 0 0" />
      <mass value="0.5" />
      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
    </inertial>
    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
  </link>
  <joint name="joint3" type="revolute">
    <origin xyz="0.28503 0 0" rpy="0 0 -1.7939" />
      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
    <parent link="link2" />
    <child link="link3" />
    <axis xyz="0 0 1" />
    <limit lower="-2.967" upper="0" effort="100" velocity="5" />
  </joint>
  <link name="link4">
    <inertial>
      <origin xyz="-9.66635791618542E-05 0.000876064475651083 -0.00496880904640868" rpy="0 0 0" />
      <mass value="0.38" />
      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
    </inertial>
    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
  </link>
  <joint name="joint4" type="revolute">
    <origin xyz="-0.021984 -0.25075 0" rpy="1.5708 0 0" />
    <parent link="link3" />
    <child link="link4" />
    <axis xyz="0 0 1" />
    <limit lower="-1.745" upper="1.745" effort="100" velocity="5" />
  </joint>
  <link name="link5">
    <inertial>
      <origin xyz="-4.10554118924211E-05 -0.0566486692356075 -0.0037205791677906" rpy="0 0 0" />
      <mass value="0.383" />
      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
    </inertial>
    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
  </link>
  <joint name="joint5" type="revolute">
    <origin xyz="0 0 0" rpy="-1.5708 0 0" />
    <parent link="link4" />
    <child link="link5" />
    <axis xyz="0 0 1" />
    <limit lower="-1.22" upper="1.22" effort="100" velocity="5" />
  </joint>
  <link name="link6">
    <inertial>
      <origin xyz="-8.82590762930069E-05 9.0598378529832E-06 -0.002" rpy="0 0 0" />
      <mass value="0.007" />
      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
    </inertial>
    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
  </link>
  <joint name="joint6" type="revolute">
    <origin xyz="8.8259E-05 -0.091 0" rpy="1.5708 0 0" />
    <parent link="link5" />
    <child link="link6" />
    <axis xyz="0 0 1" />
    <limit lower="-2.0944" upper="2.0944" effort="100" velocity="3" />
  </joint>
  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

  <link name="link_1dof">
    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
    <inertial>
      <origin xyz="0.060619 0.000301 0.037996" rpy="0 0 0"/>
      <mass value="0.068677"/>
      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
    </inertial>
  </link>

  <link name="link_1dof_2dof">
    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
    <inertial>
      <origin xyz="-0.036597 -0.056690 0.001262" rpy="0 0 0"/>
      <mass value="0.079274"/>
      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
    </inertial>
  </link>

  <link name="link_2dof">
    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
    <inertial>
      <origin xyz="-0.006523 0.044519 -0.000353" rpy="0 0 0"/>
      <mass value="0.050085"/>
      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
    </inertial>
  </link>

  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
  <joint name="link6_to_link_1dof" type="fixed">
    <parent link="link6"/>
    <child link="link_1dof"/>
    <origin xyz="-0.0000571791 0.0000250444 0.0099998" rpy="0 0 3.14159265"/>
  </joint>

  <joint name="link_1dof_2dof_joint" type="revolute">
    <parent link="link_1dof"/>
    <child link="link_1dof_2dof"/>
    <origin xyz="0.084758 0.000154 0.093298" rpy="0 0 0"/>
    <axis xyz="-1 0 0"/>
    <limit lower="-1.5708" upper="1.5708" effort="5.0" velocity="3.0"/>
    <dynamics damping="0.01" friction="0.01"/>
  </joint>

  <joint name="link_2dof_joint" type="revolute">
    <parent link="link_1dof_2dof"/>
    <child link="link_2dof"/>
    <origin xyz="-0.084454 -0.072154 0.001702" rpy="0 0 0"/>
    <axis xyz="0 1 0"/>
    <limit lower="-1.5708" upper="1.5708" effort="5.0" velocity="3.0"/>
    <dynamics damping="0.01" friction="0.01"/>
  </joint>



  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

  <link name="link_gear_1">
    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
    <inertial>
      <origin xyz="0.010063 -0.020209 0.000565" rpy="0 0 0"/>
      <mass value="0.002480"/>
      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
    </inertial>
  </link>

  <link name="link_gear_2">
    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
    <inertial>
      <origin xyz="0.010372 -0.020072 -0.000025" rpy="0 0 0"/>
      <mass value="0.002482"/>
      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
    </inertial>
  </link>

  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
  <joint name="gear_1_joint" type="revolute">
    <parent link="link_2dof"/>
    <child link="link_gear_1"/>
    <origin xyz="-0.053913 0.065516 -0.011163" rpy="0 0 0"/>
    <axis xyz="-1 0 0"/>
    <limit lower="-0.5236" upper="0.5236" effort="2.0" velocity="3.0"/>
    <dynamics damping="0.005" friction="0.005"/>
  </joint>

  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
  <joint name="gear_2_joint" type="revolute">
    <parent link="link_2dof"/>
    <child link="link_gear_2"/>
    <origin xyz="-0.054149 0.065669 0.007325" rpy="0 0 0"/>
    <axis xyz="-1 0 0"/>
    <limit lower="-0.5236" upper="0.5236" effort="2.0" velocity="3.0"/>
    <dynamics damping="0.005" friction="0.005"/>
    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
  </joint>

</robot>
